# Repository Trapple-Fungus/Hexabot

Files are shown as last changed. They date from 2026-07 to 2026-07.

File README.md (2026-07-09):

# Hexabot

A 3D-printed hexapod robot: hexagonal body with 6 radially mounted legs
(60° apart), 3 servos per leg (coxa/femur/tibia), 18 servos total, driven
by an ELEGOO UNO R3 through a PCA9685 16-channel PWM driver.

## Hardware

- **Body**: 3D-printed hexagonal plate, 227 × 186 mm and 65 mm tall
  (measured from `Body.3mf`), with six identical servo pockets around the
  perimeter ~113 mm from center, one per corner.
- **Per leg**: Miuzei MS24 270° digital servo for the coxa (hip yaw,
  vertical axis) + two 20 kg-class 270° metal-gear digital servos for the
  femur and tibia (pitch, horizontal axes). Measured from the print files:
  femur link 125 mm (~105 mm axis-to-axis), tibia part 100 mm (~140 mm
  knee-to-foot-tip with the foot).
- **Stance**: spider-like inverted-V — hip up to the knee (femur +30°
  above horizontal), then steeply down to the foot (tibia −90° off the
  femur line), foot landing ~161 mm outboard of the hip with ~69 mm of
  ground clearance below the femur axis.
- **Controller**: ELEGOO UNO R3 (Arduino Uno clone) + PCA9685 16-channel
  I2C PWM servo driver (address 0x40).

Part dimensions come from `Cad files/(C) measure_parts.py`, which prints
the bounding box of every STL/3MF in `Cad files/3D print files/` — re-run
it after reprinting parts and re-derive the gait constants if lengths
change.

Left-side legs are mirror images of right-side legs; the code handles this
with a per-leg direction-sign table.

## Servo channel map

The PCA9685 has 16 channels but the robot has 18 servos, so 5 legs live on
the board (one leg per 3 consecutive channels) and the left rear leg runs
directly off Uno pins D9/D10/D11.

| PCA9685 channel | Leg | Joint |
|---|---|---|
| CH 0 | Right front (RF) | Coxa |
| CH 1 | Right front (RF) | Femur |
| CH 2 | Right front (RF) | Tibia |
| CH 3 | Right mid (RM) | Coxa |
| CH 4 | Right mid (RM) | Femur |
| CH 5 | Right mid (RM) | Tibia |
| CH 6 | Right rear (RR) | Coxa |
| CH 7 | Right rear (RR) | Femur |
| CH 8 | Right rear (RR) | Tibia |
| CH 9 | Left front (LF) | Coxa |
| CH 10 | Left front (LF) | Femur |
| CH 11 | Left front (LF) | Tibia |
| CH 12 | Left mid (LM) | Coxa |
| CH 13 | Left mid (LM) | Femur |
| CH 14 | Left mid (LM) | Tibia |
| CH 15 | — | Spare |

| Uno pin | Leg | Joint |
|---|---|---|
| D9 | Left rear (LR) | Coxa |
| D10 | Left rear (LR) | Femur |
| D11 | Left rear (LR) | Tibia |

### PCA9685 ↔ Uno wiring

| PCA9685 pin | Connects to |
|---|---|
| VCC | Uno 5V (logic power only) |
| GND | Uno GND |
| SDA | Uno A4 |
| SCL | Uno A5 |
| V+ (screw terminal) | External 5–6.8 V high-current servo supply **+** |
| GND (screw terminal) | External servo supply **−** (shares ground with the Uno) |

**Never** power the servos from the Uno's 5V pin or USB — see Power below.

## Sketches

Both sketches need the **Adafruit PWM Servo Driver Library** (Arduino IDE →
Library Manager → search "Adafruit PWM Servo Driver").

| Sketch | Purpose |
|---|---|
| [`Hexapod/`](Hexapod/) | **The main sketch.** Full 6-leg framework: neutral standing pose on boot, tripod-gait walking (forward / backward / crab left-right / turn in place) driven over Serial, plus a live per-joint calibration UI. See its README for controls, gait math, and tuning. |
| [`RightFrontLeg/`](RightFrontLeg/) | Original single-leg test: drives one leg (PCA9685 channels 0/1/2) through a Bezier-curve triangular step cycle, one cycle per `r` over Serial. Kept as a standalone testbed for a freshly built leg. |

Both sketches drive the 270° servos with 500–2500 µs pulses via
`writeMicroseconds()` (the PCA9685's, or `Servo.h`'s for the three Uno-pin
joints), because degree-based `write()` APIs clamp to 0–180° and can't reach
the servos' full travel.

## Build status

One leg (right front) is assembled; it plugs into PCA9685 channels 0–2. The
`Hexapod` sketch ships with only that leg enabled; flip each leg's
`enabled` flag in its config table as it gets built.

## Power — read this before wiring

18× 20 kg servos draw well over 10 A under load. USB / the Uno's 5V pin
cannot power them:

- Feed a dedicated 5–6.8 V high-current supply into the PCA9685's V+ screw
  terminal, with grounds common to the Uno.
- The PCA9685 board's terminal block and traces are only rated for roughly
  5–10 A total. For the full 18-servo robot, don't run all servo current
  through the little board — distribute power (e.g., a separate heavy-gauge
  5–6.8 V bus bar feeding the servo +/− wires, with only signal pins going
  to the PCA9685) or at minimum solder heavier feed wires to the rail.
- Put a large electrolytic capacitor (1000 µF+) across the servo rail to
  absorb start-up surges.

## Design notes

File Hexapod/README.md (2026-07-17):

# Hexapod — Tripod Gait + Stance Framework

`Hexapod.ino` drives the full robot: 6 legs × 3 joints (coxa/femur/tibia),
18 servos total. On boot, every **enabled** leg moves to the neutral standing
pose (sized against the CAD-measured leg segments) and holds it. Serial
commands then walk the robot **forward, backward, sideways (crab), or turn in
place** using a tripod gait with Bezier-curve swing paths, and a calibration
UI lets you tune each joint's mechanical offset live.

## Hardware setup

The servos are driven by a **PCA9685 16-channel I2C PWM board** (default
address 0x40) wired to the Uno: VCC→5V, GND→GND, SDA→A4, SCL→A5. Since the
robot has 18 servos and the board 16 channels, five legs sit on PCA9685
channels 0–14 (one leg per 3 consecutive channels, CH15 spare) and the LR
leg runs on Uno pins D9–D11 through `Servo.h`. All pulse output goes through
the `ServoBackend` class — that is the **single swap point** if the hardware
changes (second PCA9685, Mega); nothing above it changes.

The sketch needs the **Adafruit PWM Servo Driver Library** (Arduino IDE →
Library Manager → search "Adafruit PWM Servo Driver").

### ⚠ Power

18× 20 kg-class servos can pull well over 10 A under load. USB and the Uno's
5V pin cannot supply this — even a few servos will brown-out the board. Feed
a dedicated 5–6.8 V high-current supply into the PCA9685's V+ screw terminal
(grounds common to the Uno), and for the full robot distribute the servo
current instead of running it all through the board's ~5–10 A-rated terminal
block and traces — see the power section of the [main README](../README.md).

## Serial controls (9600 baud, single characters)

### Motion

| Key | Action |
|-----|---|
| `w` / `s` | Walk forward / backward |
| `a` / `d` | Crab-walk left / right (body translates sideways, no turning) |
| `q` / `e` | Turn in place left / right |
| `x` | Stop — settles smoothly back to the neutral stance |

Motion continues until you send `x` or a different direction. Direction
changes take effect at the next half-cycle boundary (when all six feet are
on the ground), so the robot never gets yanked mid-step.

### Calibration

| Key | Action |
|-----|---|
| `0`–`5` | Select leg (0=RF 1=RM 2=RR 3=LF 4=LM 5=LR) |
| `c` / `f` / `t` | Select coxa / femur / tibia on the selected leg |
| `+` / `-` | Nudge the selected joint's offset ±2° (servo moves immediately) |
| `<` / `>` | Coarse nudge ±10° (for large horn-mount offsets) |
| `j` | Wiggle the selected joint to identify it physically |
| `v` | Move to the **calibration pose**: femur + tibia hang plumb straight down, knee locked straight |
| `z` | **Diagnostic scan**: wiggle every enabled joint in sequence, announcing each over Serial |
| `n` | Ease back to the neutral standing stance |
| `p` | Print the full offset table |
| `h` | Help |

Workflow: prop the body **at least 25 cm** off the bench (the feet hang
~245 mm below the hip axis in the calibration pose) → press `v` → for each
leg, nudge the **femur** until it hangs plumb vertical, the **tibia** until
it continues dead straight in line with it, and the **coxa** (checked from
directly above) until the leg points straight out from its body corner →
press `p` → copy the printed offsets into the `offsetDeg` fields in
`legs[]` → re-upload. Offsets are pose-independent, so values tuned in the
hanging pose are exactly right for standing and walking.

If a knee physically can't straighten all the way (bracket hits the femur),
don't force it — calibrate that tibia against a 90° square at the neutral
stance (`n`) instead.

## How the tripod gait works

The six legs are split into two tripods, each with **2 legs from one side and
1 from the other**, so the body always rests on a stable triangle:

- **Tripod A** = RF, RR, LM (legs 0, 2, 4)
- **Tripod B** = RM, LF, LR (legs 1, 3, 5)

Each half-cycle, one tripod **swings** — each foot arcs to its next foothold
along a **quadratic Bezier curve** (start → lifted apex → target, with the
control point inflated so the curve actually passes through the apex at
mid-swing, same as the single-leg sketch) — while the other tripod is in
**stance** (feet stay loaded on the ground and push the body in a straight
line). Then the roles swap. Both phases run their timing through an
ease-in-out cubic. The curved path plus the eased timing means the servos
never see a velocity discontinuity at lift-off or touch-down — that's what
keeps shock loads off the gear trains.

Every leg interpolates from *wherever it currently is* to its target, so
starting from standstill, stopping, and switching direction are all smooth —
there are no assumed start positions.

### Why sideways walking needs per-leg stride factors

The legs are mounted **radially** (60° apart, pointing outward), so a coxa
sweep moves each foot along a different real-world direction — the arc is
always perpendicular to the direction the leg points. The gait scales each
leg's coxa sweep by the projection of the desired travel direction onto that
leg's arc (`k = cos` of the angle between them):

| Motion | RF | RM | RR | LF | LM | LR |
|---|----|----|----|----|----|----|
| Forward | 0.50 | 1.00 | 0.50 | 0.50 | 1.00 | 0.50 |
| Crab right | −0.87 | 0 | 0.87 | 0.87 | 0 | −0.87 |
| Turn right | −1 | −1 | −1 | 1 | 1 | 1 |

(Backward, crab left, and turn left are the same tables negated.)

Reading the crab-right row: the front and rear legs' arcs point 30° off the
lateral axis (cos 30° ≈ 0.87), and their fore-aft components cancel between
the front and rear pair, leaving pure sideways push. The mid legs' arcs are
purely fore-aft, so they can't contribute — during crab walking they just
lift and replant in place, acting as support. Turning sweeps all feet in the
same rotational sense, which is opposite signs on opposite sides.

### Gait tuning constants (top of the sketch)

Defaults are derived from the CAD-measured leg geometry (femur ~105 mm
axis-to-axis, tibia+foot ~140 mm, hip ~113 mm from body center → foot
~274 mm from center at neutral).

| Constant | Default | Meaning |
|---|---|---|
| `STRIDE_DEG` | 20 | Coxa half-sweep at full stride factor — ~187 mm/step for mid legs; keeps adjacent feet ≥140 mm apart at full stride |
| `LIFT_FEMUR` | 10 | Femur lift at the swing apex — together with `LIFT_TIBIA` the foot rises ~39 mm |
| `LIFT_TIBIA` | 6 | Tibia fold at the swing apex (flip sign if the foot digs down instead of tucking up) |
| `GAIT_STEPS` | 30 | Interpolation steps per half-cycle — smoothness |
| `STEP_MS` | 15 | ms per step — overall speed (half-cycle ≈ 450 ms) |

## Leg layout and channels

The six legs are identical printed assemblies mounted radially — rotated
around the body, not mirrored. So femur/tibia rotate the same physical way
on both sides (`sign = +1` everywhere) and only the **coxa** direction flips
on the left (`sign = −1`), because "sweep toward the front" reverses when
the leg points the other way. Each leg occupies 3 consecutive PCA9685
channels; the LR leg overflows the 16-channel board onto Uno pins.

| # | Leg | Coxa | Femur | Tibia | Tripod | Enabled by default |
|---|-----|---|---|---|---|---|
| 0 | RF (right front) | CH0 | CH1  | CH2  | A | ✅ |
| 1 | RM (right mid) | CH3 | CH4  | CH5  | B | ✅ |
| 2 | RR (right rear)  | CH6 | CH7  | CH8  | A | ✅ |
| 3 | LF (left front)  | CH9 | CH10 | CH11 | B | ✅ |
| 4 | LM (left mid) | CH12 | CH13 | CH14 | A | ✅ |
| 5 | LR (left rear) | Uno D9 | Uno D10 | Uno D11 | B | ✅ |

CH15 is spare. All six legs are enabled in `legs[]`; set a leg's `enabled`
flag to `false` if it isn't built or wired yet. The full channel-by-channel
table and the PCA9685↔Uno wiring are in the [main README](../README.md).

## If some legs don't move

The sketch sends pulses to **every enabled joint on every gait step** — a leg
that never moves is a hardware problem, not a gait problem. Diagnose in this
order:

1. **Check the boot banner.** The Serial Monitor must say `Hexapod fw build 3`.
   If it says `Leg ready. Press 'r'...` you are running the old single-leg
   `RightFrontLeg.ino` test sketch — which only ever drives CH0–CH2. Upload
   `Hexapod.ino` instead.
2. **Check the boot I2C scan line.** It must list `0x40`. If it doesn't, the
   PCA9685 is miswired or strapped to a different address, and every PCA
   channel is dead.
3. **Send `z`.** Every joint wiggles in sequence with its name and channel
   printed. A servo that stays still on its turn: wrong channel plug, dead
   servo, or no servo power on V+.
4. **If joints move one at a time (`z`) but sag or freeze when walking**, the
   servo supply is browning out under the combined load — see the power
   section of the main README.

## Logical angle convention

All poses are written in body-frame logical degrees; the per-leg `sign` and
`offsetDeg` translate them to raw servo positions.

- **Coxa**: `0°` = leg pointing radially outward from its body corner.
  Positive sweeps the leg toward the robot's front.
- **Femur**: `0°` = horizontal. Positive lifts the knee up.
- **Tibia**: `0°` = in line with the femur (leg straight). Negative bends
  the foot down toward the ground.

The neutral stance (knee up, foot below and outboard), sized against the
measured leg segments for a **3 in (76 mm) belly clearance**:

```cpp
const LegPose NEUTRAL = { 0, 15, -90 };  // coxa, femur, tibia
```

With femur ≈ 105 mm and tibia+foot ≈ 140 mm this puts the foot ~138 mm
outboard of the hip and **~108 mm below the femur axis**; with the femur
axis at the 65 mm body's mid-height, the body plate rides ~76 mm ≈ 3 in
off the ground. (The previous `{0, 30, −90}` stance stood ~36 mm.)

Calibrate the offsets first, then measure the real standing height —
the trim knob is the femur angle: **1° less femur ≈ 2.4 mm taller**, and
vice versa. The tibia angle changes height much more slowly (~0.6 mm/°)
at this pose, so leave it at −90 unless the stance width needs changing.

Mapping to a servo: `servoDeg = 135 + sign × logicalDeg + offsetDeg`, then
converted to a 500–2500 µs pulse across 270° and sent as microseconds to
the PCA9685 (or via `Servo.writeMicroseconds()` for the LR leg's Uno pins) —
degree-based `write()` APIs clamp to 180° and can't use these servos' full
range.

## Bring-up order

1. With only RF enabled, verify the neutral stance and calibrate its offsets.
2. Send `w` and watch RF step through the gait in the air — sanity-check the
   swing direction and foot clearance before other legs exist.
3. Build and enable the remaining legs one at a time, calibrating each.
4. Before enabling more than a couple of legs, sort out servo power: a
   dedicated 5–6.8 V high-current supply on the PCA9685's V+ terminal, and
   distributed power wiring for the full 18-servo load (see the main
   README's power section).
5. First full-robot walk: prop the body on a box so the feet hang free, run
   each motion, and only then put it on the ground.

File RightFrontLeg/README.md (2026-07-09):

# Right Front Leg — Bezier Walking Test

This sketch (`RightFrontLeg.ino`) drives a single hexapod leg (3 servos: coxa, femur,
tibia) through a triangular foot path using Bezier-curve motion, so the servos ease
in and out instead of snapping between positions.

> **Note:** full-robot walking now lives in [`../Hexapod/`](../Hexapod/), which
> handles all 6 legs with a tripod gait (forward/backward/crab/turn). This sketch
> is kept as a standalone testbed for exercising a freshly built leg in isolation.

## Hardware as described

- 3D-printed black leg assembly with a triangular truss link at the top.
- Two Miuzei 20kg digital servos (4.8V–6.8V) in series for the femur/tibia joints,
  plus a third servo for the coxa (hip rotation).
- ELEGOO UNO R3 (Arduino Uno clone) + PCA9685 16-channel I2C PWM driver
  (VCC→5V, GND→GND, SDA→A4, SCL→A5, default address 0x40).
- Servo power comes from an external 5–6.8 V supply on the PCA9685's V+
  screw terminal (ground common with the Uno) — not from USB or the Uno's
  5V pin.
- Needs the **Adafruit PWM Servo Driver Library** (Arduino IDE → Library
  Manager).

## Channel assignment

The test channels match the RF leg's slots in the full Hexapod sketch, so a
freshly built leg plugs straight into the board. Change the `*_CH` constants
at the top of the sketch to test a leg on other channels.

| Joint | PCA9685 channel |
|---|---|
| Coxa  | CH0 |
| Femur | CH1 |
| Tibia | CH2 |

## Degree convention (logical angles used in the code)

These are the angles the code's math is written in terms of — they are **not**
necessarily the raw `servo.write()` degrees, see Calibration below.

- **Coxa**: `90°` = leg pointing straight out, matching the resting pose in the
  reference photo. Less than 90° sweeps the leg one way (toward the rear),
  more than 90° sweeps it the other way (toward the front).
- **Femur**: `0°` = pointing straight down (vertical). Increasing the angle lifts
  the femur up/forward.
- **Tibia**: `0°` = in line with the femur (leg fully extended/straight).
  Increasing the angle bends the knee joint.

## Calibration offsets

Real servos rarely have their mechanical zero land exactly on the logical zero
above. `COXA_OFFSET`, `FEMUR_OFFSET`, and `TIBIA_OFFSET` (top of the sketch, all
`0` by default) are added to the logical angle before it's sent to the servo:

```cpp
int deg = (int)round(logicalDeg) + offset;
deg = constrain(deg, 0, SERVO_MAX_DEG);
int us = map(deg, 0, SERVO_MAX_DEG, SERVO_MIN_US, SERVO_MAX_US);
s.writeMicroseconds(us);
```

If, say, your femur servo's true "vertical down" position is actually
75° rather than 0°, set `FEMUR_OFFSET = 75`. Tune these first, against the leg's
real resting pose, before touching anything else — the trajectory math always
works purely in logical angles.

### Why microsecond pulses instead of degree APIs

These are 270° servos, but degree-based servo APIs clamp their input to
0–180° before mapping it to a pulse width — they physically cannot reach past
180° no matter what you pass them. To use the full sweep, logical degrees
(0–270, `SERVO_MAX_DEG`) are mapped straight to a pulse width in microseconds
and sent with `pwm.writeMicroseconds(channel, us)` on the PCA9685.
`SERVO_MIN_US`/`SERVO_MAX_US` (default `500`/`2500`) are typical for 270°
hobby servos but aren't guaranteed for your exact model — if a servo buzzes,
stalls, or stops short of where you told it to go, narrow this range and
re-check against the datasheet. If all servos are consistently off by the
same proportion, the PCA9685's internal oscillator (nominally 27 MHz, but it
varies board to board) is the culprit — trim `PCA_OSC_HZ` at the top of the
sketch.

## How the motion works

The foot is driven around a triangle made of three corner poses (each a
coxa/femur/tibia angle triple), defined near the top of the file:

- `GROUND_BACK` — foot down, swept toward the rear. End of stance / start of swing.
- `LIFT_APEX` — foot raised, swept to the middle. The top corner of the triangle.
- `GROUND_FRONT` — foot down, swept toward the front. End of swing / start of stance.

```cpp
LegPose GROUND_BACK  = { 40,  50,  40 };
LegPose LIFT_APEX    = { 80,  265, 90 };
LegPose GROUND_FRONT = { 120, 50,  40 };
```

These values are still being tuned against the real leg — adjust them further
as needed (see Tuning below). Note the femur apex (`265°`) is right up against
the servo's `270°` hard limit, so there's very little headroom left before it
strains; back it off if the servo buzzes or stalls there.

Each full cycle (`loop()`) has two phases:

1. **Swing phase** — `GROUND_BACK → LIFT_APEX → GROUND_FRONT`, driven as a
   **quadratic Bezier curve** over `SWING_STEPS` (default 30) steps. This is the
   part where the foot is off the ground, lifting and arcing forward.
   - A plain quadratic Bezier only gets *pulled toward* its middle control point,
     it doesn't pass through it. The code compensates by inflating the control
     point (`control = 2*LIFT_APEX - 0.5*(GROUND_BACK + GROUND_FRONT)`) so the
     curve actually reaches `LIFT_APEX` at the midpoint (`t = 0.5`) of the swing.
2. **Stance phase** — `GROUND_FRONT → GROUND_BACK`, driven as a straight linear
   interpolation over `STANCE_STEPS` (default 30) steps. This is the part where
   the foot is loaded on the ground and (once the full hexapod is built) pushes
   the body forward — it intentionally stays low and straight rather than curving.

Both phases pass their progress `t` (0 → 1) through an **ease-in-out cubic**
function before interpolating:

```cpp
float easeInOutCubic(float t) {
  return (t < 0.5f) ? 4*t*t*t : 1 - pow(-2*t + 2, 3) / 2;
}
```

This is what actually protects the servos: it removes the instantaneous
start/stop velocity change at the beginning and end of each phase, so the servo
accelerates and decelerates smoothly instead of jerking. The Bezier shape gives
the *path* a curve; the easing gives the *timing along that path* a curve — both
together are what reduce mechanical stress.

`STEP_DELAY_MS` (default 15ms) sets the delay between each step and therefore the
overall speed of the gait cycle.

## Triggering the cycle with 'r'

The leg no longer runs continuously. On `setup()` it moves to `GROUND_BACK` and
then idles, holding that pose, until it receives the character `r` (or `R`) over
Serial — at which point it runs exactly one full swing+stance cycle and goes back
to idling.

To trigger it: open the Arduino IDE's Serial Monitor (Tools → Serial Monitor) at
9600 baud, type `r`, and hit Enter. Each press runs one more cycle. Any other
character is ignored. This is handled in `loop()` by `Serial.available()` /
`Serial.read()`, with the actual cycle logic factored out into `runGaitCycle()`.

## Tuning the leg

1. Upload the sketch. On `setup()` it moves straight to `GROUND_BACK` and holds
   there so you can check the resting pose before triggering any movement.
2. Watch the swing phase — adjust `LIFT_APEX`'s femur/tibia angles until the foot
   clears the ground by the amount you want without overdriving the servo.
3. Adjust `GROUND_BACK` and `GROUND_FRONT`'s coxa angles to set how far the leg
   sweeps back and forward (stride length).
4. Adjust `STEP_DELAY_MS` and the `*_STEPS` constants to change gait speed/smoothness
   (more steps + lower delay-per-step = smoother but same total time; fewer steps =
   choppier).

## Next steps

Full hexapod walking is implemented in [`../Hexapod/`](../Hexapod/): the same
swing/stance approach runs on all 6 legs with two tripod groups (RF/RR/LM and
RM/LF/LR) 180° out of phase — one tripod swings while the other pushes, then
they swap. Once a new leg passes its solo test with this sketch, plug it into
its PCA9685 channels from the Hexapod README's channel table and flip its
`enabled` flag there.

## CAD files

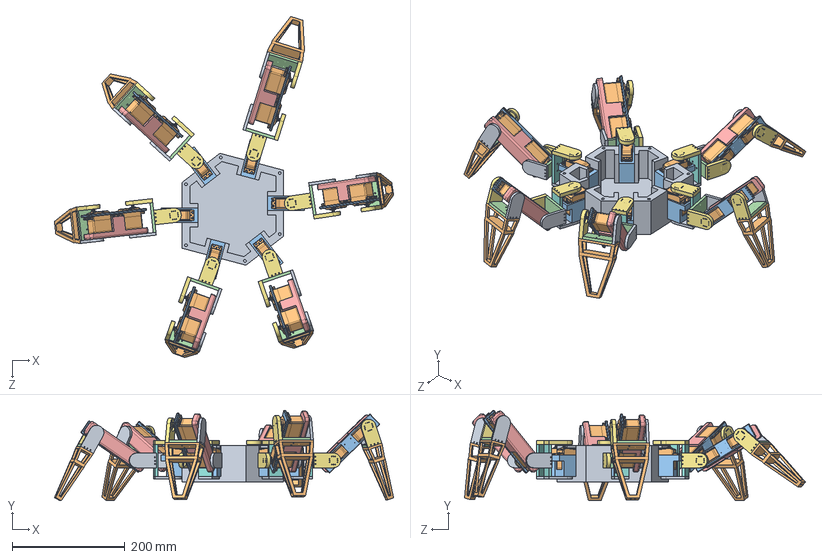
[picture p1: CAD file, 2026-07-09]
Cad files/hexabot.SLDASM
601.9 x 160.5 x 605.0 mm
Moter holder 1 x 6
LewanSoul LD-20M Servo 20kg x 18
Bracket (bottom) x 18
bracket (middle) x 6
Bracket (top) x 18
middle motor holder x 6
Bracket (middle 2) x 12
top motor holder x 6
tibia x 6

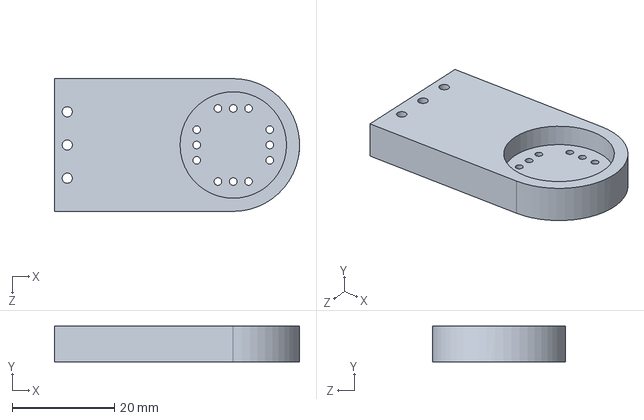
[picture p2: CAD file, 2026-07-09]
Cad files/Bracket (top).SLDPRT
48.0 x 7.00 x 26.0 mm

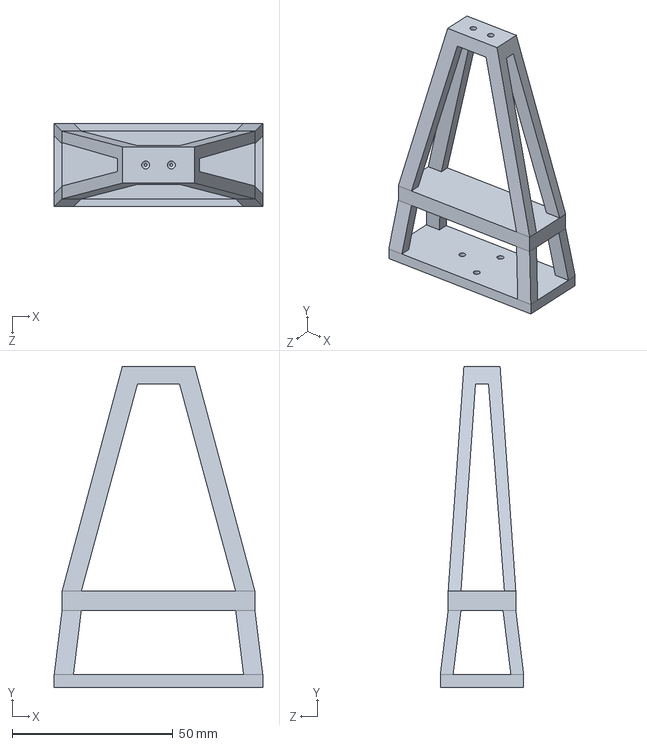
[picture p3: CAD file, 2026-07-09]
Cad files/tibia.SLDPRT
65.0 x 100.0 x 26.0 mm

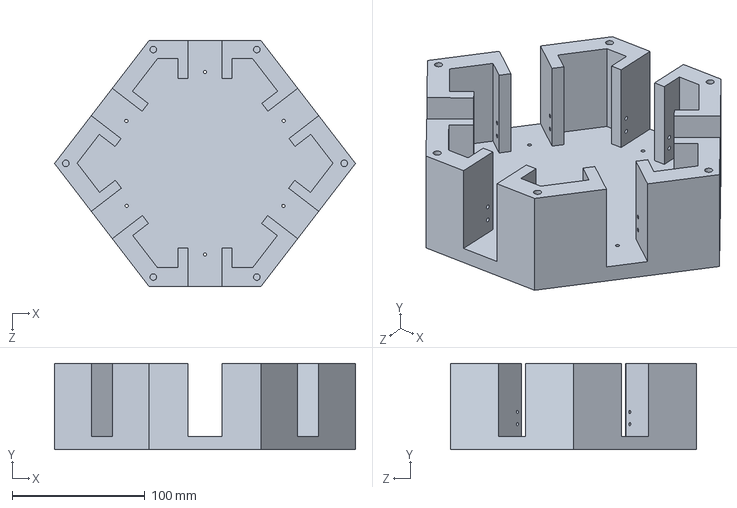
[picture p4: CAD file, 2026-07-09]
Cad files/Body.SLDPRT
227.0 x 65.0 x 185.5 mm

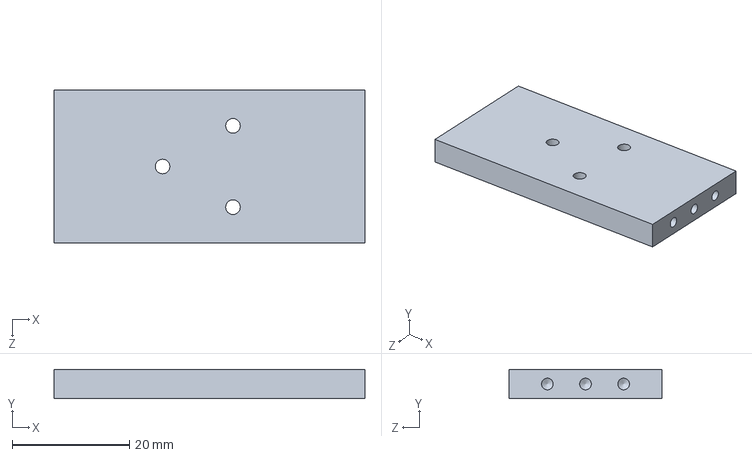
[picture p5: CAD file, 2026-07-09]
Cad files/Bracket (middle 2).SLDPRT
53.0 x 5.00 x 26.0 mm

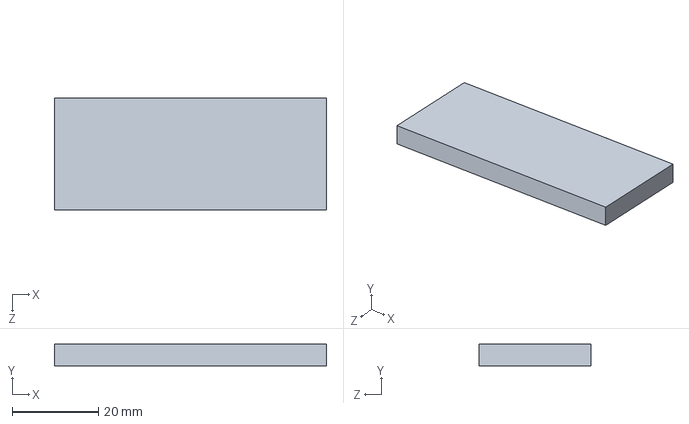
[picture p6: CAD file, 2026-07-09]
Cad files/foot.SLDPRT
63.0 x 5.00 x 26.0 mm

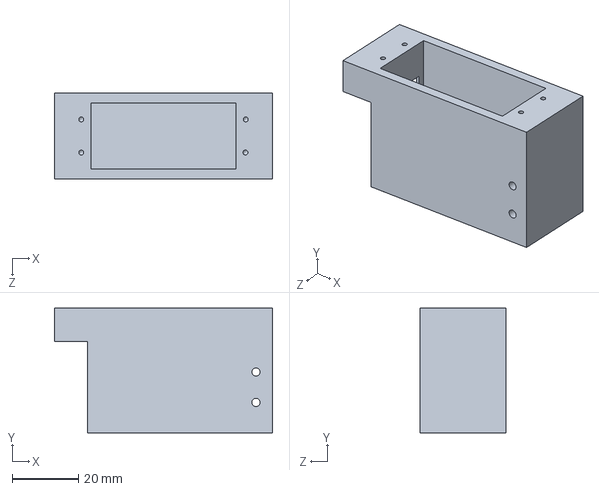
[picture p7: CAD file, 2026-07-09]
Cad files/Moter holder 1.SLDPRT
66.0 x 37.7 x 26.0 mm

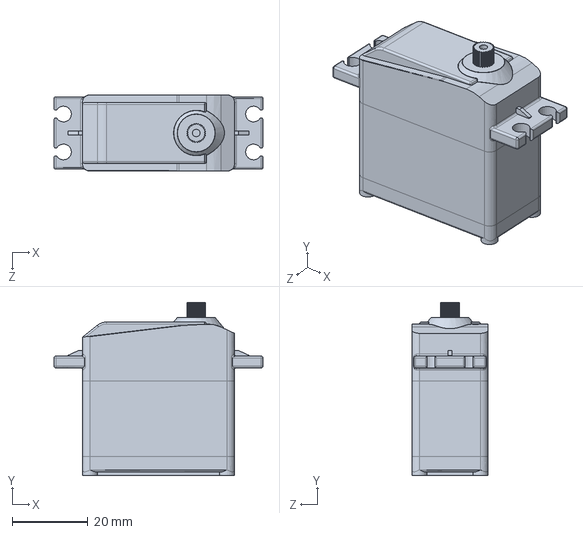
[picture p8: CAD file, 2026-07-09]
Cad files/LewanSoul LD-20M Servo 20kg.SLDPRT
55.1 x 45.7 x 20.1 mm

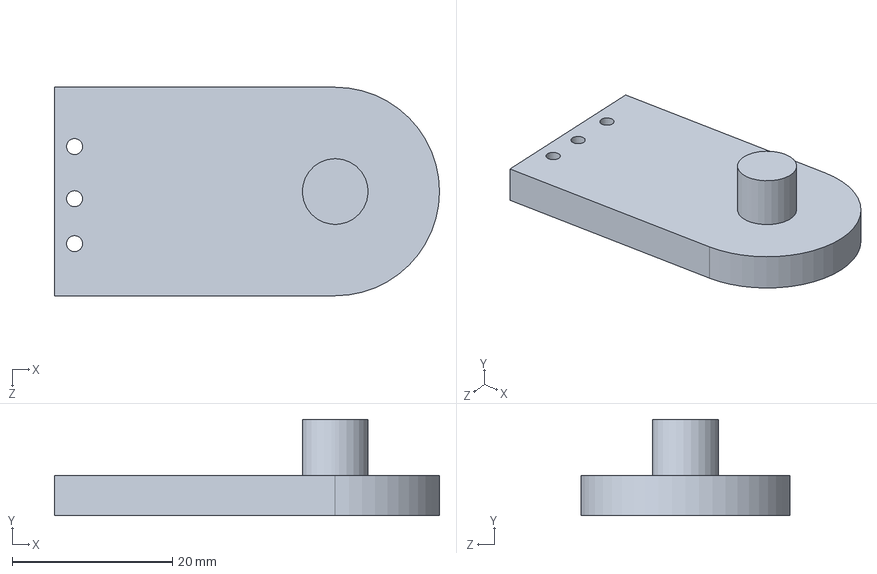
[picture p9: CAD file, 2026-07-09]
Cad files/Bracket (bottom).SLDPRT
48.0 x 12.0 x 26.0 mm

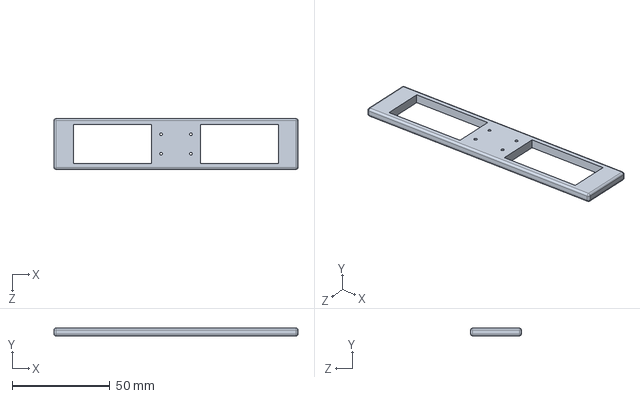
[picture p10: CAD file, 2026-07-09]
Cad files/top motor holder.SLDPRT
125.0 x 4.00 x 26.0 mm

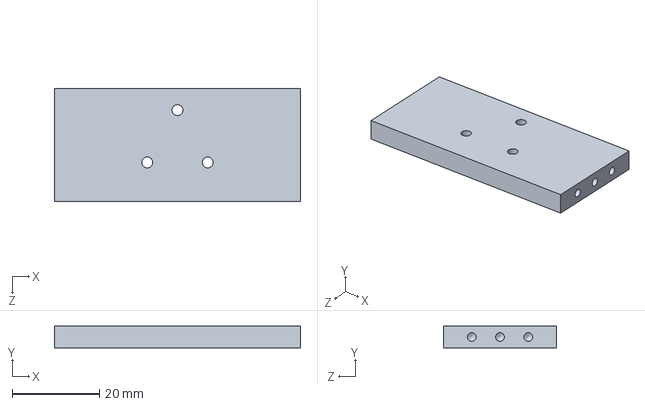
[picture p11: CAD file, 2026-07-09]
Cad files/bracket (middle).SLDPRT
56.4 x 5.00 x 26.0 mm

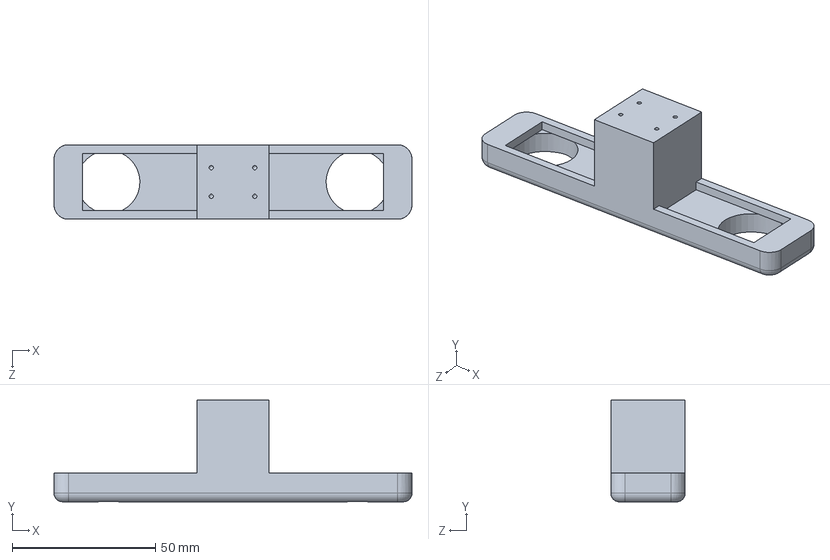
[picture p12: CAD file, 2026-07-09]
Cad files/middle motor holder.SLDPRT
125.0 x 35.5 x 26.0 mm

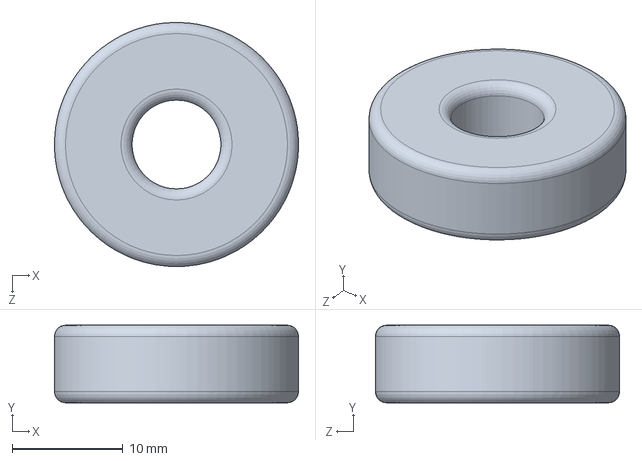
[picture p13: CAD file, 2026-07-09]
Cad files/Part2.SLDPRT
22.0 x 7.00 x 22.0 mm

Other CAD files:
Cad files/3D print files/Body.3mf
Cad files/3D print files/Bracket (bottom).STL
Cad files/3D print files/Bracket (middle 2).STL
Cad files/3D print files/Bracket (top).STL
Cad files/3D print files/Moter holder 1.3mf
Cad files/3D print files/Moter holder 1.STL
Cad files/3D print files/bracket (middle).STL
Cad files/3D print files/middle motor holder.STL
Cad files/3D print files/tibia.STL
Cad files/3D print files/top motor holder.STL

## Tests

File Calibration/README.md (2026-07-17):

# Calibration — Static Reference Pose

`Calibration.ino` does exactly one thing: on power-up it drives **all 18
servos to the calibration pose and holds it**, so you can walk around the
robot and instantly see which joints are right and which are off.

Every leg should look identical:

| Joint | Target |
|---|---|
| Coxa  | Leg points **straight out** from its body corner (check from directly above) |
| Femur | Hanging **plumb straight down** (compare against a hanging string or the body's vertical side) |
| Tibia | **Dead straight** in line with the femur — the whole leg is one vertical line, no kink at the knee |

## ⚠ Before powering up

- **Prop the body at least 25 cm off the bench.** The legs extend fully
  downward — feet hang ~245 mm below the hip axis. On the desk, the robot
  will do a push-up and fall over.
- Servos snap to the pose at full speed the moment power arrives (there is
  no soft-start on a cold boot — the first pulse a servo sees *is* the
  target). Keep fingers clear.
- Same wiring as the Hexapod sketch: PCA9685 at 0x40 (SDA=A4, SCL=A5),
  legs on CH0–14, LR leg on Uno D9–D11, servo power on V+.

## Fixing a joint that's off

The `legs[]` table (channels, signs, `offsetDeg`) is **identical in layout
to `Hexapod.ino`'s** — keep the two in sync:

1. Small error (a few degrees → ~25°): find the offset. Either tune it live
   in the Hexapod sketch (`v` pose + `+`/`-` keys, then `p`), or edit
   `offsetDeg` here, re-upload, and look again. Repeat until plumb.
2. Large error (> ~40°): re-mount the servo horn a spline tooth or two
   instead — the horns only mount in ~14.4° steps, and big offsets eat the
   servo's usable travel in one direction.
3. When the pose is perfect, copy the final `offsetDeg` values into
   `Hexapod.ino`'s `legs[]` so walking uses them too.

The Serial Monitor (9600 baud) prints the exact pulse width sent to every
joint at boot — useful for confirming a servo that isn't moving is at least
being commanded.

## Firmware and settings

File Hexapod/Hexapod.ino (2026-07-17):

#include <Wire.h>
#include <Adafruit_PWMServoDriver.h>  // Adafruit PWM Servo Driver Library
#include <Servo.h>                    // fallback for the LR leg on Uno pins

// ============================================================
// Hexapod: 6 legs x 3 joints (coxa/femur/tibia), 18 servos.
//
// On boot every enabled leg moves to the neutral standing pose
// and holds it. Serial commands then drive a tripod gait —
// forward / backward / crab left / crab right / turn — plus a
// live calibration UI for tuning per-joint offsets.
//
// Tripod gait: legs are split into two groups of three that
// always contain 2 legs from one side + 1 from the other:
//   Tripod A = RF, RR, LM    Tripod B = RM, LF, LR
// One tripod swings through the air toward its next foothold
// while the other pushes on the ground, then they swap. The
// body is always supported by a stable 3-point triangle.
//
// Servo backend: a PCA9685 16-channel I2C PWM driver (SDA=A4,
// SCL=A5, address 0x40) carries 15 of the 18 joints — one leg
// per 3 consecutive channels, CH0-CH14. The 18th-16th joint
// overflow (the whole LR leg) runs on Uno pins D9-D11 via
// Servo.h. All pulse output funnels through the ServoBackend
// class, so different hardware (a second PCA9685, a Mega) only
// touches that class.
// ============================================================

// ---- 270-degree servo pulse range ----
// Servo::write() clamps to 0-180, so logical degrees are mapped to
// microseconds directly and sent with writeMicroseconds(). Typical
// values for 270-degree hobby servos; narrow the range if a servo
// buzzes or stalls at either end.
const int SERVO_MIN_US     = 500;
const int SERVO_MAX_US     = 2500;
const int SERVO_MAX_DEG    = 270;
const int SERVO_CENTER_DEG = 135;  // logical 0 deg maps here

// ---- PCA9685 setup ----
const int      SERVO_FREQ_HZ = 50;        // standard 20 ms servo frame
const uint32_t PCA_OSC_HZ    = 27000000;  // nominal internal oscillator — it
                                          // varies board to board, so trim this
                                          // if measured pulses run long/short

// ---- Leg geometry (measured from the CAD 3D-print files) ----
// Femur link (motor holder parts): 125 mm part, ~105 mm axis-to-axis.
// Tibia part: 100 mm, ~140 mm knee axis to foot tip with the foot on.
// Body: 227 x 186 mm hex plate, hip pockets ~113 mm from center.
// The sketch works purely in joint angles — these numbers are what the
// pose and gait constants below were derived from, so re-derive those
// if the printed parts change.
const float FEMUR_MM = 105;
const float TIBIA_MM = 140;

const int NUM_LEGS   = 6;
const int NUM_JOINTS = 3;
enum Joint { COXA = 0, FEMUR = 1, TIBIA = 2 };

// ---- Logical angle convention (degrees) ----
//   coxa  : 0 = leg pointing radially outward from its body corner,
//           positive = sweeps toward the robot's front
//   femur : 0 = horizontal, positive = knee lifts up
//   tibia : 0 = in line with the femur, negative = bends down toward
//           the ground
struct LegPose {
  float coxa;
  float femur;
  float tibia;
};

// Standing pose, sized against the measured leg (femur ~105 mm axis to
// axis, tibia+foot ~140 mm) for a 3 in (76 mm) belly clearance: femur
// +15 deg with the tibia -90 deg off the femur line puts the foot
// ~138 mm outboard of the hip and ~108 mm below the femur axis. With
// the femur axis at the 65 mm body's mid-height, the body plate rides
// ~76 mm off the ground. (The previous {0,30,-90} stance was ~36 mm.)
// Trim knob: 1 deg LESS femur = body ~2.4 mm HIGHER, and vice versa.
// Measure the real standing height and trim, since both the horn
// offsets and the hip-axis-height assumption move this number.
const LegPose NEUTRAL = { 0, 15, -90 };

// Calibration pose ('v' command): femur and tibia both plumb straight
// down with the knee locked straight — trivially easy to eyeball
// against gravity or the body's vertical sides. Offsets are
// pose-independent, so values tuned here are exactly right for
// walking. The feet hang ~245 mm below the hip axis in this pose:
// prop the body at least that high off the bench BEFORE pressing 'v'.
const LegPose CALIB_POSE = { 0, -90, 0 };

// ---- Per-leg configuration ----
// sign flips a joint's direction. The six legs are identical printed
// assemblies (the CAD has one variant of each part) bolted radially
// around the body — rotated, not mirrored. Rotating a leg about the
// body's vertical axis preserves "up", so femur/tibia rotate the same
// way on both sides (+1 everywhere); only the coxa flips on the left,
// because "sweep toward the front" reverses when the leg points the
// other way. (Build 3 and earlier flipped all three joints on the
// left, which drove left knees down whenever the right knees lifted.)
// offsetDeg absorbs each individual servo's mechanical zero error —
// tune it with the serial UI below, then copy the printed values back
// into this table so they persist across uploads.
struct JointConfig {
  uint8_t channel;    // PCA9685 channel (0-15), or Uno pin when onUno is set
  bool    onUno;      // 18 joints > 16 channels: the LR leg lives on Uno pins
  int8_t  sign;       // +1 or -1
  int16_t offsetDeg;
};

struct LegConfig {
  const char* name;
  bool enabled;       // only attach/drive legs that are physically built
  JointConfig joint[NUM_JOINTS];
};

// One leg per 3 consecutive PCA9685 channels; CH15 is spare. The LR
// leg overflows the 16-channel board onto Uno pins D9/D10/D11 (the
// same pins the original single-leg build used, so old wiring fits).
LegConfig legs[NUM_LEGS] = {
  // name  enabled   coxa                 femur                tibia
  { "RF",  true,  {{ 0, false, +1, 0}, { 1, false, +1, 0}, { 2, false, +1, 0}} },
  { "RM",  true,  {{ 3, false, +1, 0}, { 4, false, +1, 0}, { 5, false, +1, 0}} },
  { "RR",  true,  {{ 6, false, +1, 0}, { 7, false, +1, 0}, { 8, false, +1, 0}} },
  { "LF",  true,  {{ 9, false, -1, 0}, {10, false, +1, 0}, {11, false, +1, 0}} },
  { "LM",  true,  {{12, false, -1, 0}, {13, false, +1, 0}, {14, false, +1, 0}} },
  { "LR",  true,  {{ 9, true,  -1, 0}, {10, true,  +1, 0}, {11, true,  +1, 0}} },
};

// Tripod A = RF, RR, LM (legs 0, 2, 4) — 2 right + 1 left.
// Tripod B = RM, LF, LR (legs 1, 3, 5) — 1 right + 2 left.
const bool TRIPOD_A[NUM_LEGS] = { true, false, true, false, true, false };

// ---- Gait tuning (derived from the measured geometry) ----
const float STRIDE_DEG = 20;  // coxa half-sweep at full stride factor:
                              // ~187 mm/step for mid legs at the 274 mm
                              // foot radius, and adjacent feet stay
                              // >=140 mm apart at full stride (25 deg
                              // was 271 mm steps with only 107 mm gap)
const float LIFT_FEMUR = 10;  // swing-apex lift; with LIFT_TIBIA = 6 the
const float LIFT_TIBIA = 6;   // foot rises ~39 mm — clears the ground
                              // without wasting servo travel (the old
                              // 25/20 lifted ~120 mm every step). Tibia
                              // positive folds the foot up toward the
                              // femur line — flip the sign if your foot
                              // digs down instead
const int   GAIT_STEPS = 30;  // interpolation steps per half-cycle
const int   STEP_MS    = 15;  // ms per step (speed of the gait)

// ---- Per-leg stride factors ----
// The legs point radially outward (60 deg apart), so a coxa sweep moves
// each foot along a different real-world arc. Each motion direction
// scales every leg's coxa sweep by the projection of that direction
// onto the leg's arc: k = cos(angle between desired travel and the
// leg's tangent). Corner legs sit 60 deg off the fore-aft axis
// (cos 60 = 0.5) and 30 deg off the lateral axis (cos 30 = 0.87);
// mid legs are fully fore-aft (1.0 forward, 0 sideways).
//
// Sign convention: positive k means the foot lands toward the robot's
// front at swing end, then pushes rearward during stance.
//                                      RF     RM    RR     LF     LM    LR
const float K_FORWARD[NUM_LEGS] = {  0.50f, 1.0f, 0.50f, 0.50f, 1.0f, 0.50f };
const float K_RIGHT[NUM_LEGS]   = { -0.87f, 0.0f, 0.87f, 0.87f, 0.0f, -0.87f };
const float K_TURN_R[NUM_LEGS]  = { -1.0f, -1.0f, -1.0f,  1.0f, 1.0f,  1.0f };

enum Motion { STOP, FORWARD, BACKWARD, CRAB_LEFT, CRAB_RIGHT, TURN_LEFT, TURN_RIGHT };
Motion motion = STOP;

float strideFactor(Motion m, uint8_t li) {
  switch (m) {
    case FORWARD:    return  K_FORWARD[li];
    case BACKWARD:   return -K_FORWARD[li];
    case CRAB_RIGHT: return  K_RIGHT[li];
    case CRAB_LEFT:  return -K_RIGHT[li];
    case TURN_RIGHT: return  K_TURN_R[li];
    case TURN_LEFT:  return -K_TURN_R[li];
    default:         return 0;
  }
}

// ---- Servo backend ----
// The single swap point for the servo hardware: PCA9685 channels for
// most joints, a small Servo.h pool for the Uno-pin overflow (LR leg).
// A second PCA9685 or a Mega would only change the code in this class.
class ServoBackend {
public:
  void begin() {
    pwm.begin();
    pwm.setOscillatorFrequency(PCA_OSC_HZ);
    pwm.setPWMFreq(SERVO_FREQ_HZ);
    Wire.setClock(400000);  // 15 I2C writes per gait step; 100 kHz is too slow
    for (int l = 0; l < NUM_LEGS; l++)
      for (int j = 0; j < NUM_JOINTS; j++)
        unoHandle[l][j] = -1;
    unoUsed = 0;
  }

  // The first pulse a servo ever sees is the target pose, not an
  // uncommanded jump: PCA9685 channels are silent until first written,
  // and Uno-pin servos get writeMicroseconds() before attach().
  bool attach(uint8_t leg, uint8_t j, const JointConfig &jc, int initialUs) {
    if (!jc.onUno) {
      pwm.writeMicroseconds(jc.channel, initialUs);
      return true;
    }
    if (unoUsed >= MAX_UNO_SERVOS) return false;
    unoHandle[leg][j] = unoUsed;
    unoPool[unoUsed].writeMicroseconds(initialUs);
    unoPool[unoUsed].attach(jc.channel, SERVO_MIN_US, SERVO_MAX_US);
    unoUsed++;
    return true;
  }

  void writeUs(uint8_t leg, uint8_t j, const JointConfig &jc, int us) {
    if (!jc.onUno) {
      pwm.writeMicroseconds(jc.channel, us);
      return;
    }
    int8_t h = unoHandle[leg][j];
    if (h >= 0) unoPool[h].writeMicroseconds(us);
  }

private:
  Adafruit_PWMServoDriver pwm;             // default I2C address 0x40
  static const uint8_t MAX_UNO_SERVOS = 3; // just the LR leg overflow
  Servo   unoPool[MAX_UNO_SERVOS];
  int8_t  unoHandle[NUM_LEGS][NUM_JOINTS];
  uint8_t unoUsed;
};

ServoBackend backend;
LegPose currentPose[NUM_LEGS];

int jointToUs(const JointConfig &jc, float logicalDeg) {
  float servoDeg = SERVO_CENTER_DEG + jc.sign * logicalDeg + jc.offsetDeg;
  servoDeg = constrain(servoDeg, 0, SERVO_MAX_DEG);
  return map((int)round(servoDeg), 0, SERVO_MAX_DEG, SERVO_MIN_US, SERVO_MAX_US);
}

void applyLegPose(uint8_t li, const LegPose &p) {
  currentPose[li] = p;
  if (!legs[li].enabled) return;
  backend.writeUs(li, COXA,  legs[li].joint[COXA],  jointToUs(legs[li].joint[COXA],  p.coxa));
  backend.writeUs(li, FEMUR, legs[li].joint[FEMUR], jointToUs(legs[li].joint[FEMUR], p.femur));
  backend.writeUs(li, TIBIA, legs[li].joint[TIBIA], jointToUs(legs[li].joint[TIBIA], p.tibia));
}

LegPose lerpPose(const LegPose &a, const LegPose &b, float t) {
  LegPose r;
  r.coxa  = a.coxa  + (b.coxa  - a.coxa)  * t;
  r.femur = a.femur + (b.femur - a.femur) * t;
  r.tibia = a.tibia + (b.tibia - a.tibia) * t;
  return r;
}

// Quadratic Bezier through p0 / control p1 / p2 — the swing-phase path,
// same approach as the single-leg test sketch.
LegPose bezierPose(const LegPose &p0, const LegPose &p1, const LegPose &p2, float t) {
  float u = 1.0f - t;
  LegPose r;
  r.coxa  = u * u * p0.coxa  + 2 * u * t * p1.coxa  + t * t * p2.coxa;
  r.femur = u * u * p0.femur + 2 * u * t * p1.femur + t * t * p2.femur;
  r.tibia = u * u * p0.tibia + 2 * u * t * p1.tibia + t * t * p2.tibia;
  return r;
}

// Eases velocity at the start/end of each phase instead of an instant
// start/stop, which is the main thing that shock-loads the servos.
float easeInOutCubic(float t) {
  return (t < 0.5f) ? 4 * t * t * t : 1 - pow(-2 * t + 2, 3) / 2;
}

// ---- Gait engine ----
// One half-cycle: the swinging tripod lifts and arcs to its forward
// foothold along a quadratic Bezier curve (start -> lifted apex ->
// target) while the stance tripod stays down and pushes the body in a
// straight line. The Bezier plus the ease-in-out timing means the
// servos see no velocity discontinuities at lift-off or touch-down —
// that's what keeps shock loads off the gears. Every leg interpolates
// from wherever it currently is to its target, so starting from
// neutral, stopping, and changing direction at a half-cycle boundary
// are all smooth — no assumed start positions.
void runHalfCycle(bool aSwings, Motion m) {
  LegPose start[NUM_LEGS], target[NUM_LEGS], control[NUM_LEGS];
  for (uint8_t li = 0; li < NUM_LEGS; li++) {
    start[li]  = currentPose[li];
    target[li] = NEUTRAL;
    float dir = (TRIPOD_A[li] == aSwings) ? +1 : -1;  // swing lands front, stance pushes rear
    target[li].coxa += dir * strideFactor(m, li) * STRIDE_DEG;

    // Swing apex = midpoint of the move plus the lift. A plain quadratic
    // Bezier only gets pulled toward its control point, it doesn't pass
    // through it, so the control point is inflated
    // (2*apex - 0.5*(start+target)) to make the curve actually hit the
    // apex at t = 0.5 — same trick as the single-leg sketch.
    LegPose apex = lerpPose(start[li], target[li], 0.5f);
    apex.femur += LIFT_FEMUR;
    apex.tibia += LIFT_TIBIA;
    control[li].coxa  = 2 * apex.coxa  - 0.5f * (start[li].coxa  + target[li].coxa);
    control[li].femur = 2 * apex.femur - 0.5f * (start[li].femur + target[li].femur);
    control[li].tibia = 2 * apex.tibia - 0.5f * (start[li].tibia + target[li].tibia);
  }

  for (int i = 0; i <= GAIT_STEPS; i++) {
    float t = easeInOutCubic((float)i / GAIT_STEPS);
    for (uint8_t li = 0; li < NUM_LEGS; li++) {
      // Swinging feet arc through the air on the Bezier; stance feet are
      // loaded on the ground, so they move low and straight instead.
      LegPose p = (TRIPOD_A[li] == aSwings)
                    ? bezierPose(start[li], control[li], target[li], t)
                    : lerpPose(start[li], target[li], t);
      applyLegPose(li, p);
    }
    delay(STEP_MS);
  }
}

// Eases all legs from wherever they are to a target pose — used for
// stopping, the 'n' neutral command, and the 'v' calibration pose, so
// none of them snap the servos.
void moveAllTo(const LegPose &target) {
  LegPose start[NUM_LEGS];
  for (uint8_t li = 0; li < NUM_LEGS; li++)
    start[li] = currentPose[li];
  for (int i = 0; i <= GAIT_STEPS; i++) {
    float t = easeInOutCubic((float)i / GAIT_STEPS);
    for (uint8_t li = 0; li < NUM_LEGS; li++)
      applyLegPose(li, lerpPose(start[li], target, t));
    delay(STEP_MS);
  }
}

void returnToNeutral() {
  moveAllTo(NEUTRAL);
  Serial.println(F("Stopped — neutral stance."));
}

// ---- Serial UI ----
// Motion (single characters, Serial Monitor at 9600 baud):
//   w/s      walk forward / backward
//   a/d      crab-walk left / right
//   q/e      turn in place left / right
//   x        stop (settle back to neutral stance)
// Calibration:
//   0-5      select leg (0=RF 1=RM 2=RR 3=LF 4=LM 5=LR)
//   c f t    select joint on the selected leg
//   + -      nudge the selected joint's offset by +/-2 deg (moves live)
//   < >      coarse nudge by +/-10 deg (for large horn-mount offsets)
//   j        wiggle the selected joint to identify it physically
//   n        re-apply the neutral stance to all enabled legs
//   p        print the offset table (copy values back into legs[])
//   h        print this help
uint8_t selLeg   = 0;
uint8_t selJoint = COXA;

const char* jointName(uint8_t j) {
  return j == COXA ? "coxa" : (j == FEMUR ? "femur" : "tibia");
}

void printHelp() {
  Serial.println(F("Motion:  w fwd | s back | a crab left | d crab right"));
  Serial.println(F("         q turn left | e turn right | x stop"));
  Serial.println(F("Calibrate: 0-5 leg | c/f/t joint | +/- nudge 2deg | </> 10deg"));
  Serial.println(F("           v calib pose (legs plumb down) | j wiggle joint"));
  Serial.println(F("           n neutral | p print offsets | h help"));
  Serial.println(F("Diagnose:  z wiggle every joint in sequence (finds dead wiring)"));
}

void printSelection() {
  Serial.print(F("Selected: leg "));
  Serial.print(legs[selLeg].name);
  Serial.print(F(" / "));
  Serial.print(jointName(selJoint));
  Serial.print(F("  offset="));
  Serial.println(legs[selLeg].joint[selJoint].offsetDeg);
}

void printOffsets() {
  Serial.println(F("Offsets (coxa, femur, tibia):"));
  for (int li = 0; li < NUM_LEGS; li++) {
    Serial.print(legs[li].name);
    Serial.print(legs[li].enabled ? F("  ") : F(" (disabled) "));
    for (int j = 0; j < NUM_JOINTS; j++) {
      Serial.print(legs[li].joint[j].offsetDeg);
      Serial.print(j < NUM_JOINTS - 1 ? F(", ") : F("\n"));
    }
  }
}

void nudgeOffset(int delta) {
  legs[selLeg].joint[selJoint].offsetDeg += delta;
  applyLegPose(selLeg, currentPose[selLeg]);  // re-send with new offset
  printSelection();
}

// Wiggles one joint +/-15 deg, then settles back — the quick way to
// check that a servo is plugged into the channel the legs[] table says
// it is.
void wiggleOne(uint8_t li, uint8_t j, int cycles) {
  LegPose base = currentPose[li];
  const int steps = 20;
  for (int cycle = 0; cycle < cycles; cycle++) {
    for (int i = 0; i <= steps; i++) {
      float wave = 15.0f * sin(2 * PI * i / steps);
      LegPose p = base;
      if      (j == COXA)  p.coxa  += wave;
      else if (j == FEMUR) p.femur += wave;
      else                 p.tibia += wave;
      applyLegPose(li, p);
      delay(STEP_MS * 2);
    }
  }
  applyLegPose(li, base);
}

void wiggleJoint() {
  printSelection();
  wiggleOne(selLeg, selJoint, 3);
}

// Wiggles every enabled joint in sequence, announcing each over Serial.
// This is the first thing to run when legs aren't moving: a joint that
// stays still here has a wiring/power/channel problem, not a gait
// problem — the exact pulse the gait would send is being sent to it.
void scanAllJoints() {
  Serial.println(F("Joint scan — watch each named servo wiggle:"));
  for (uint8_t li = 0; li < NUM_LEGS; li++) {
    if (!legs[li].enabled) {
      Serial.print(legs[li].name);
      Serial.println(F(" skipped (disabled)"));
      continue;
    }
    for (uint8_t j = 0; j < NUM_JOINTS; j++) {
      const JointConfig &jc = legs[li].joint[j];
      Serial.print(legs[li].name);
      Serial.print(' ');
      Serial.print(jointName(j));
      Serial.print(jc.onUno ? F(" (Uno D") : F(" (CH"));
      Serial.print(jc.channel);
      Serial.println(')');
      wiggleOne(li, j, 1);
    }
  }
  Serial.println(F("Scan done. Any joint that stayed still: check its plug,"));
  Serial.println(F("channel number, and servo power — the code did drive it."));
}

void setMotion(Motion m, const __FlashStringHelper* name) {
  motion = m;
  Serial.print(F("Motion: "));
  Serial.println(name);
}

void handleCommand(char c) {
  // Motion keys
  if      (c == 'w' || c == 'W') setMotion(FORWARD,    F("forward"));
  else if (c == 's' || c == 'S') setMotion(BACKWARD,   F("backward"));
  else if (c == 'a' || c == 'A') setMotion(CRAB_LEFT,  F("crab left"));
  else if (c == 'd' || c == 'D') setMotion(CRAB_RIGHT, F("crab right"));
  else if (c == 'q' || c == 'Q') setMotion(TURN_LEFT,  F("turn left"));
  else if (c == 'e' || c == 'E') setMotion(TURN_RIGHT, F("turn right"));
  else if (c == 'x' || c == 'X') setMotion(STOP,       F("stop"));
  // Calibration keys
  else if (c >= '0' && c <= '5') { selLeg = c - '0'; printSelection(); }
  else if (c == 'c' || c == 'C') { selJoint = COXA;  printSelection(); }
  else if (c == 'f' || c == 'F') { selJoint = FEMUR; printSelection(); }
  else if (c == 't' || c == 'T') { selJoint = TIBIA; printSelection(); }
  else if (c == '+') { nudgeOffset(+2); }
  else if (c == '-') { nudgeOffset(-2); }
  else if (c == '>') { nudgeOffset(+10); }
  else if (c == '<') { nudgeOffset(-10); }
  else if (c == 'j' || c == 'J') { wiggleJoint(); }
  else if (c == 'z' || c == 'Z') { scanAllJoints(); }
  else if (c == 'n' || c == 'N') {
    moveAllTo(NEUTRAL);
    Serial.println(F("Neutral stance applied."));
  }
  else if (c == 'v' || c == 'V') {
    moveAllTo(CALIB_POSE);
    Serial.println(F("Calibration pose: femur + tibia plumb straight down."));
    Serial.println(F("(Body must be propped >= 25 cm up — feet hang ~245 mm.)"));
  }
  else if (c == 'p' || c == 'P') { printOffsets(); }
  else if (c == 'h' || c == 'H') { printHelp(); }
  // anything else (newlines etc.) is ignored
}
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
void loop() {
  while (Serial.available() > 0)
    handleCommand(Serial.read());

  if (motion == STOP) {
    // Settle back to neutral exactly once after a stop. (Checking for
    // STOP after runHalfCycle() never fired: commands are only read at
    // the top of loop(), so the robot froze in its last gait posture.)
    if (!settled) {
      returnToNeutral();
      settled = true;
    }
    return;
  }
  settled = false;

  // Latch the motion for this half-cycle so a direction change can't
  // yank the stride factors mid-air; new commands take effect at the
  // next half-cycle boundary, when all six feet are on the ground.
  Motion m = motion;
  runHalfCycle(aSwings, m);
  aSwings = !aSwings;
}

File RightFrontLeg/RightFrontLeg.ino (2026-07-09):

#include <Wire.h>
#include <Adafruit_PWMServoDriver.h>  // Adafruit PWM Servo Driver Library

// ============================================================
// Single-leg test sketch: right-front coxa/femur/tibia leg.
// Drives the foot through a triangular path (lift -> swing
// forward -> ground contact -> drag back) using a quadratic
// Bezier curve for the swing phase, so the servos accelerate
// and decelerate smoothly instead of snapping between angles.
//
// Servos are driven by a PCA9685 16-channel I2C PWM board
// (SDA=A4, SCL=A5, address 0x40), matching the full Hexapod
// sketch's wiring — the RF leg's channels double as the test
// channels, so a leg under test plugs straight into CH0-CH2.
// ============================================================

// ---- PCA9685 channel assignment ----
// Point these at whichever channels the leg under test is plugged into.
const int COXA_CH  = 0;
const int FEMUR_CH = 1;
const int TIBIA_CH = 2;

const int      SERVO_FREQ_HZ = 50;        // standard 20 ms servo frame
const uint32_t PCA_OSC_HZ    = 27000000;  // nominal; trim if pulses run long/short

Adafruit_PWMServoDriver pwm;  // default I2C address 0x40

// ---- Calibration offsets ----
// Logical angle convention used throughout this sketch:
//   coxa  : 90 deg = leg pointing straight out (as in the reference photo)
//   femur : 0  deg = vertically down
//   tibia : 0  deg = in line with the femur (leg fully extended)
// If your servo's physical zero doesn't actually land on that pose,
// adjust the offset here rather than touching the trajectory math below.
const int COXA_OFFSET  = 0;
const int FEMUR_OFFSET = 0;
const int TIBIA_OFFSET = 0;

// ---- 270-degree servo pulse range ----
// Logical degrees (0-270) are mapped straight to a pulse width in
// microseconds and sent with pwm.writeMicroseconds(), so the servos'
// full travel is usable. These pulse widths are typical for 270-degree
// hobby servos but check your servo's datasheet and tune if it
// buzzes/stalls at either end.
const int SERVO_MIN_US = 500;
const int SERVO_MAX_US = 2500;
const int SERVO_MAX_DEG = 270;

struct LegPose {
  float coxa;
  float femur;
  float tibia;
};

void writeJoint(int channel, float logicalDeg, int offset) {
  int deg = (int)round(logicalDeg) + offset;
  deg = constrain(deg, 0, SERVO_MAX_DEG);
  int us = map(deg, 0, SERVO_MAX_DEG, SERVO_MIN_US, SERVO_MAX_US);
  pwm.writeMicroseconds(channel, us);
}

void applyPose(const LegPose &p) {
  writeJoint(COXA_CH, p.coxa, COXA_OFFSET);
  writeJoint(FEMUR_CH, p.femur, FEMUR_OFFSET);
  writeJoint(TIBIA_CH, p.tibia, TIBIA_OFFSET);
}

LegPose lerpPose(const LegPose &a, const LegPose &b, float t) {
  LegPose r;
  r.coxa  = a.coxa  + (b.coxa  - a.coxa)  * t;
  r.femur = a.femur + (b.femur - a.femur) * t;
  r.tibia = a.tibia + (b.tibia - a.tibia) * t;
  return r;
}

LegPose bezierPose(const LegPose &p0, const LegPose &p1, const LegPose &p2, float t) {
  float u = 1.0f - t;
  LegPose r;
  r.coxa  = u * u * p0.coxa  + 2 * u * t * p1.coxa  + t * t * p2.coxa;
  r.femur = u * u * p0.femur + 2 * u * t * p1.femur + t * t * p2.femur;
  r.tibia = u * u * p0.tibia + 2 * u * t * p1.tibia + t * t * p2.tibia;
  return r;
}

// Eases velocity at the start/end of each phase instead of an instant
// start/stop, which is the main thing that shock-loads small servos.
float easeInOutCubic(float t) {
  return (t < 0.5f) ? 4 * t * t * t : 1 - pow(-2 * t + 2, 3) / 2;
}

// ---- Triangle corner poses (tune these to your leg's real range) ----
// GROUND_BACK  : foot down, swept toward the rear  -> end of stance / start of swing
// LIFT_APEX    : foot raised, swept to the middle  -> top corner of the triangle
// GROUND_FRONT : foot down, swept toward the front -> end of swing / start of stance
LegPose GROUND_BACK  = { 40,  80, 60 };
LegPose LIFT_APEX    = { 80,  150, 90 };
LegPose GROUND_FRONT = { 180, 80, 60 };

const int SWING_STEPS   = 30;  // resolution of the Bezier swing arc
const int STANCE_STEPS  = 30;  // resolution of the ground push-back
const int STEP_DELAY_MS = 15;  // time between steps -> overall cycle speed

void runGaitCycle() {
  // ---- Swing phase: Bezier arc GROUND_BACK -> LIFT_APEX -> GROUND_FRONT ----
  // A plain quadratic Bezier only gets pulled toward its control point,
  // it doesn't pass through it. Inflating the control point like this
  // makes the curve actually hit LIFT_APEX at t = 0.5.
  LegPose control;
  control.coxa  = 2 * LIFT_APEX.coxa  - 0.5f * (GROUND_BACK.coxa  + GROUND_FRONT.coxa);
  control.femur = 2 * LIFT_APEX.femur - 0.5f * (GROUND_BACK.femur + GROUND_FRONT.femur);
  control.tibia = 2 * LIFT_APEX.tibia - 0.5f * (GROUND_BACK.tibia + GROUND_FRONT.tibia);

  for (int i = 0; i <= SWING_STEPS; i++) {
    float t = easeInOutCubic((float)i / SWING_STEPS);
    applyPose(bezierPose(GROUND_BACK, control, GROUND_FRONT, t));
    delay(STEP_DELAY_MS);
  }

  // ---- Stance phase: straight ground drag GROUND_FRONT -> GROUND_BACK ----
  // This is the part of the cycle where the foot is loaded and pushing
  // the body forward, so it stays low and moves in a straight line
  // instead of another curve.
  for (int i = 0; i <= STANCE_STEPS; i++) {
    float t = easeInOutCubic((float)i / STANCE_STEPS);
    applyPose(lerpPose(GROUND_FRONT, GROUND_BACK, t));
    delay(STEP_DELAY_MS);
  }
}

void setup() {
  Serial.begin(9600);
  pwm.begin();
  pwm.setOscillatorFrequency(PCA_OSC_HZ);
  pwm.setPWMFreq(SERVO_FREQ_HZ);
  Wire.setClock(400000);
  // PCA9685 channels emit no pulses until first written, so this first
  // applyPose() is the first thing the servos see — no uncommanded jump.
  applyPose(GROUND_BACK);
  Serial.println("Leg ready. Press 'r' in the Serial Monitor and hit Enter to run a gait cycle.");
}

void loop() {
  // Idle holding GROUND_BACK until 'r' arrives over Serial, then run one
  // full swing+stance cycle. Any other characters (e.g. the newline sent
  // along with 'r') are ignored.
  if (Serial.available() > 0) {
    char c = Serial.read();
    if (c == 'r' || c == 'R') {
      runGaitCycle();
    }
  }
}

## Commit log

2026-06-19 Front right leg movemet
2026-07-09 CAD files + 3D print files
    [Body.3mf, Body.SLDPRT, Bracket (bottom).SLDPRT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]
